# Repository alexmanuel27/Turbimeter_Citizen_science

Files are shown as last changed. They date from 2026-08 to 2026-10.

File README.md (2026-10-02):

# Citizen-science turbidimeter

This repository tracks a **single, quantitative turbidimeter prototype**. The
target is to have the instrument, Android app, calibration, and validation
ready by **18 October 2026**. Community deployment follows that date.

## Current design target

- **Sensor:** 850 nm IR LED, BPW34 photodiode at 90° for scattered light, and
  a second BPW34 to monitor the LED. An MCP6002 dual amplifier and ADS1115
  read the two channels; a Seeed XIAO SAMD21 controls the LED.
- **Readout:** the Android phone supplies power through USB-C, displays the
  result, and will offer optional upload to the citizen-science website. The
  instrument has no battery, screen, or status LEDs.
- **Enclosure:** closed body with a fixed 2 m USB-C data cable through one M12
  cable gland. The technician cuts the sensor-side plug, routes the cable,
  then terminates and tests power, USB data, and USB-C configuration wiring
  before sealing. The selected cable has a 5.5 ± 0.15 mm outer diameter;
  the gland grips 3–6.5 mm cable.
- **Output:** a numeric NTU value is a *goal*, not a property of the current
  firmware. Dark-corrected scattered/reference readings must first be
  calibrated with known standards and validated on independent samples.

The [optical and validation plan](docs/optical-design.md) describes the work
remaining. The [one-unit shopping list](docs/shopping-list-prototype-usb-c.xlsx)
is in English, shows VAT-inclusive prices and full supplier URLs as text, and
totals **€76.52** for priced items. Calibration standards require a quote;
delivery is excluded. The PCB and cuvettes are already available, so they are
not in the list. Confirm the lid groove before buying or using the selected
O-ring assortment.

## Repository status

| Path | Status |
| --- | --- |
| [`docs/optical-design.md`](docs/optical-design.md) | Current design and validation plan |
| [`docs/BOM.md`](docs/BOM.md) | Procurement notes; workbook above is the purchase list |
| [`firmware/xiao_samd21_turbimeter/`](firmware/xiao_samd21_turbimeter/) | Current XIAO optical bench firmware; reports diagnostic counts and an uncalibrated ratio over USB |
| [`firmware/firmware.ino`](firmware/firmware.ino) | Experimental optical-index sketch; still uses TL072 and status LEDs, so it is **not** the final USB-C/NTU firmware |
| [`android-app/`](android-app/) | Android USB-CDC screen/controller prototype with a XIAO SAMD21 communication test |
| [`firmware/legacy_sen0189/`](firmware/legacy_sen0189/) | Original DFRobot SEN0189 firmware, retained for reference |
| [`hardware/`](hardware/) and [`3D/`](3D/) | Earlier PCB and enclosure files; mechanical/electrical revisions are pending |
| [`docs/diagrams/legacy-circuit-schematic.svg`](docs/diagrams/legacy-circuit-schematic.svg) | Earlier TL072 circuit illustration, not a build schematic for this design |

The original SEN0189 prototype is shown below. It is superseded by the
discrete 90° optical design.

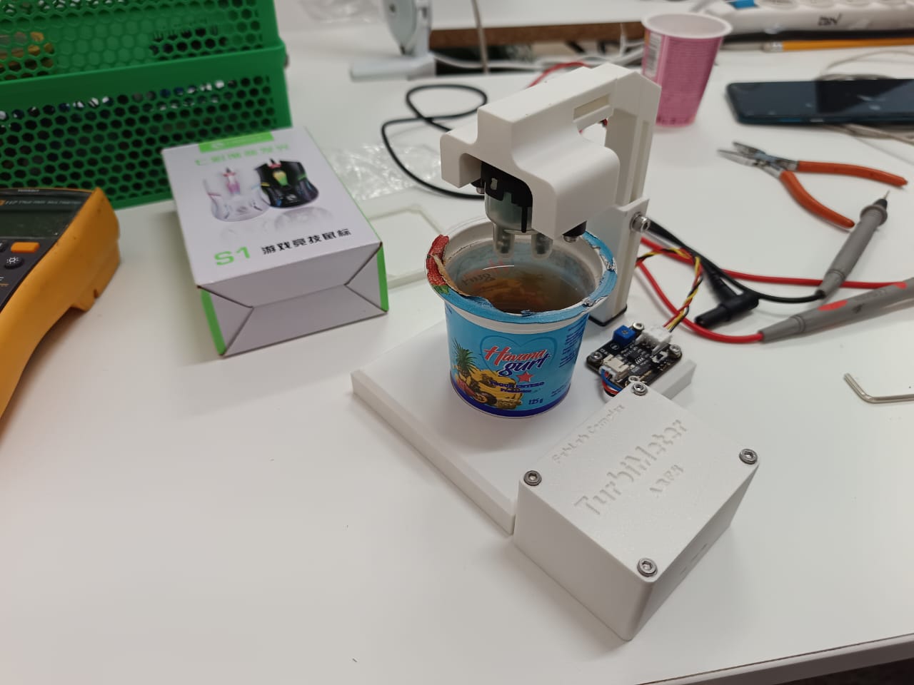
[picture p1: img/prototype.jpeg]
Earlier SEN0189 prototype


## Before 18 October

1. Bench-test the LED, both photodiodes, MCP6002, ADS1115, and feedback
   values with the actual sample chamber.
2. Revise the PCB and enclosure, choose a lid seal that fits the final groove,
   and verify USB-C power/data plus cable-gland sealing.
3. Test the new XIAO firmware and Android app together on a USB-C phone; add
   optional upload when the citizen-science API is specified.
4. Calibrate against known turbidity standards, quantify repeatability and
   error across the intended range, and only then enable NTU reporting.

Community deployment is the phase after 18 October.

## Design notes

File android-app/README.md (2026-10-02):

# Android app

The Android phone is the turbidimeter's screen and controller. This first
version connects to a USB-CDC XIAO SAMD21 and requests a reading. The side
menu has Home, History, Signature, and Privacy. Each real reading is saved automatically
in local History with its UTC timestamp and calibration status; History can be
shared as CSV. Demo readings are never saved. Signature stores
a self-declared contributor name and optional institution on the phone.
Privacy explains local data handling and lets the user delete saved data.

The **Upload reading** button appears on Home after a real reading. Uncalibrated
ratios cannot be uploaded. The citizen-science API is not defined yet, so the
app does not send data or request location permission. When the API is added,
each upload must use a fresh upload timestamp and phone location, with explicit
location permission, plus the saved contributor identity. Upload stays an
optional user action.

## Try it now

1. Flash [`usb_cdc_smoke_test.ino`](../firmware/usb_cdc_smoke_test/usb_cdc_smoke_test.ino)
   to the XIAO SAMD21 using the [Seeed Arduino setup](https://wiki.seeedstudio.com/Seeeduino-XIAO/).
2. Open this `android-app` folder in Android Studio, install Android SDK 36 if
   prompted, and run the app on an Android phone with USB host support.
3. Connect the XIAO with a **data-capable USB-C cable**. Tap **Connect sensor**,
   grant USB permission, then tap **Measure now**. The board sends a changing demo
   ratio; the app labels it as test data and does not allow saving it.

For the real optical bench, upload
[`xiao_samd21_turbimeter.ino`](../firmware/xiao_samd21_turbimeter/xiao_samd21_turbimeter.ino)
instead. It reads the ADS1115 and reports an uncalibrated ratio or a specific
sensor error. Its [wiring and test steps](../firmware/xiao_samd21_turbimeter/README.md)
must be checked before connecting the analog circuit.

For the final sealed instrument, the cable cut and passed through the gland
still needs a sound electrical termination at the board's USB-C connection.
Test the complete cable and the intended Android phone before sealing.

## Serial contract, version 1

The app sends one ASCII line: `MEASURE\n`. The device sends one ASCII line in
response. USB packets may split a line; the app assembles lines before parsing.

| Response | Meaning |
| --- | --- |
| `TURB1,DEMO,0.2500` | Synthetic value for testing USB and the screen |
| `TURB1,RATIO,0.2500` | Real optical ratio, still uncalibrated |
| `TURB1,RESULT,12.30,FNU,CAL-001,OK` | Future calibrated result with unit and calibration ID |
| `TURB1,ERROR,ADC_MISSING` | Example hardware error shown by the app |

The app rejects incomplete/nonfinite values and saves real `RATIO` and `RESULT`
frames automatically, recording their quality status in the CSV. The measurement firmware must not emit `RESULT` until its
calibration and valid measurement range have been verified. For this 850 nm
near-infrared design, decide the reportable unit and range during validation.

Saved readings remain private on the phone and can be shared manually as CSV.
The release app has no network permission or endpoint configured yet.

## Google Play preparation

See [`play-store/release-checklist.md`](play-store/release-checklist.md) for the
store assets, unsigned AAB build, privacy-policy draft, and remaining account,
signing, screenshots, and closed-testing steps.

## Check the parser without Android

With a JDK installed, run from `android-app`:

```sh
mkdir -p /tmp/turbimeter-parser
javac -d /tmp/turbimeter-parser app/src/main/java/org/citizenscience/turbimeter/{MeasurementFrame,LineFramer}.java test/MeasurementFrameCheck.java
java -ea -cp /tmp/turbimeter-parser org.citizenscience.turbimeter.MeasurementFrameCheck
```

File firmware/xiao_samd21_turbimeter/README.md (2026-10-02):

# XIAO SAMD21 optical firmware

Upload [`xiao_samd21_turbimeter.ino`](xiao_samd21_turbimeter.ino) to the
**original Seeed Studio XIAO SAMD21** (Arduino board: **Seeeduino XIAO**).
This is the current USB-C bench firmware. The older
[`firmware.ino`](../firmware.ino) targets a Nano/TL072/indicator-LED circuit;
do not upload it for this build.

## Planned wiring to verify with the electronics technician

| XIAO / sensor | Connection |
| --- | --- |
| USB-C | Power and USB CDC data from the Android phone or test computer |
| 3V3, GND | Common 3.3 V supply and ground for ADS1115 and MCP6002 |
| D4 (SDA), D5 (SCL) | ADS1115 I²C; ADDR to GND gives address `0x48` |
| D7 | Control of the current-limited 850 nm LED circuit |
| ADS1115 AIN0 | MCP6002 output from the 90° scatter photodiode |
| ADS1115 AIN1 | MCP6002 output from the LED reference photodiode |

**Do not reuse the old 5 V Nano wiring unchanged.** XIAO GPIO and I²C are
3.3 V. Power the ADS1115/MCP6002 analog circuit at 3.3 V for this test, and
confirm the LED resistor/driver current and both amplifier output ranges before
connecting them. The old PCB and drawing are not the final XIAO circuit.
See the [XIAO pin map](https://wiki.seeedstudio.com/Seeeduino-XIAO/),
[ADS1115 datasheet](https://www.ti.com/lit/ds/symlink/ads1115.pdf), and
[MCP6002 specifications](https://www.microchip.com/en-us/product/MCP6002).

## Upload and first tests

1. In Arduino IDE, add Seeed's boards URL
   `https://files.seeedstudio.com/arduino/package_seeeduino_boards_index.json`,
   install **Seeed SAMD Boards**, select **Seeeduino XIAO** and its USB port,
   then open this `.ino` and click **Upload**. The sketch needs only `Wire.h`.
2. With the XIAO connected to a computer, open Serial Monitor at **115200 baud**
   with **Newline** line ending. Send `PING`; expect `TURB1,PONG`. Send
   `MEASURE` before wiring the ADC; expect `TURB1,ERROR,ADC_MISSING`.
3. After wiring, send `DIAG`. The reply is
   `TURB1,DIAG,darkScatter,litScatter,darkReference,litReference,ratio`.
   The four signals are averaged ADS1115 counts (0.125 mV/count at the chosen
   gain). Check that the LED changes both channels, the reference difference
   is clearly above the noise, and neither input approaches 26000 counts.
4. Send `MEASURE`; expect `TURB1,RATIO,<number>`. Then connect the XIAO to an
   Android USB-C phone, tap **Connect sensor** and **Measure now** in the app.

The sketch takes four LED-off/on samples per request, subtracts the dark
signals, and divides corrected scatter by corrected reference. Adjust the two
`*_POLARITY` constants if an amplifier output falls rather than rises when
illuminated; use `DIAG` to decide. `MIN_REFERENCE_COUNTS`,
`SATURATION_COUNTS`, and `LED_SETTLE_MS` are bench settings to revisit after
measuring the actual circuit. I²C failures, weak reference, negative scatter,
and near-rail signals return explicit `TURB1,ERROR,...` messages to the app.

**Bench result, 2 October 2026:** this sketch uploaded and verified on the
connected XIAO. `PING` returned `TURB1,PONG`; `MEASURE` and `DIAG` both
returned `TURB1,ERROR,ADC_MISSING`, as expected with only the XIAO plugged in.
The ADS1115 and optical circuit were not connected, so no optical reading has
been verified yet.

**The ratio is not turbidity in FNU/NTU.** The firmware deliberately sends no
`TURB1,RESULT` until standards, a calibration curve, valid range, and
independent-sample checks have been completed. The XIAO USB link has been
checked; ADC and optical readings still need physical verification.

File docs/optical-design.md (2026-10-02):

# Optical design and validation plan

## Target and status

Build one closed turbidimeter that an Android USB-C phone powers and reads.
The app will show a quantitative turbidity value and optionally upload it to the
citizen-science website. The instrument has no battery, screen, or status
LEDs. **The optical bench, firmware, app, and NTU calibration are not yet
validated.** They must be ready before 18 October 2026; community deployment
comes afterward.

The DFRobot SEN0189 sensor and its firmware are retained only as an earlier
prototype. The current KiCad PCB and 3D files also predate this design. The
[one-unit purchase list](shopping-list-prototype-usb-c.xlsx) is the source for
current parts, supplier URLs, and VAT-inclusive prices.

## Optical and electrical concept

90-degree optical geometry

An 850 nm IR LED illuminates the sample. One BPW34 photodiode measures light
scattered at 90°; a second, shielded from the sample, monitors the LED. Read
both photodiodes with the LED off and on, subtract the dark readings, and form
a scattered/reference ratio. This ratio compensates for some changes in LED
output, but **it is not an NTU value** by itself.

The intended signal chain is:

| Stage | Planned part / connection |
| --- | --- |
| Illumination | 850 nm IR LED controlled by XIAO SAMD21 D7 through a verified current-limited circuit |
| Detection | Two BPW34 photodiodes: 90° scatter and shielded reference |
| Amplification | MCP6002 dual amplifier at 3.3 V; start with 1 MΩ feedback resistors and tune using measured signal levels |
| Conversion | ADS1115 at 3.3 V, with the two amplifier outputs on AIN0 and AIN1; I²C to XIAO D4/D5 |
| Phone interface | USB-C XIAO SAMD21, data-capable 2 m USB-C cable, Android USB host app |

Prototype the analog chain and verify input range, saturation, ambient-light
rejection, and repeatability before revising the PCB. The old
[`legacy-circuit-schematic.svg`](diagrams/legacy-circuit-schematic.svg) uses a
TL072 and status LEDs; it is **not** a schematic for this build. Likewise,
[`firmware/firmware.ino`](../firmware/firmware.ino) is the older sketch that
outputs a relative index and controls LEDs. The current USB bench sketch is
[`xiao_samd21_turbimeter.ino`](../firmware/xiao_samd21_turbimeter/xiao_samd21_turbimeter.ino).

## Enclosure and USB cable

Use the Goobay 66508 USB-C-to-USB-C data cable (2 m). Its specified outer
diameter is **5.5 ± 0.15 mm**; the selected TinyTronics M12 gland clamps
**3–6.5 mm** cable. Cut the device-side plug, pass the cable through the
gland, and terminate USB power, USB 2.0 data, and the required USB-C CC
connection to the board. Confirm continuity, Android USB host operation,
strain relief, and sealing before closing the enclosure. Verify final lid
dimensions before selecting an O-ring from the assortment (maximum 28 mm
inner diameter).

## From optical ratio to reliable NTU

1. Fix the final optical geometry and record LED-off/LED-on readings from both
   channels, including the clear-water background.
2. Measure known turbidity standards spanning the intended range with the
   same sample vessels and handling procedure. The Hanna HI98703-11 set is a
   purchase candidate; check ULB stock, vessel compatibility, and quote.
3. Fit a calibration curve only after inspecting the measured response.
   Store its coefficients and calibration identity with the device/app data.
4. Check independent samples and repeat measurements. Record the range,
   error, repeatability, drift, and any region where the sensor saturates.
5. Show/upload NTU only when the calibration is valid for that range; otherwise
   label the reading as an uncalibrated optical ratio or out of range.

The Android app prototype is present, but the citizen-science API has not yet
been specified. Upload must remain optional. A published measurement record
should include the reading, unit, calibration identity, timestamp, and quality
status.

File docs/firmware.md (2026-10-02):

# Firmware explanation (legacy SEN0189 design)

> ⚠️ **Legacy.** This describes the original DFRobot SEN0189-based sensor,
> now superseded by a custom discrete 90° nephelometric design — see
> [docs/optical-design.md](optical-design.md). Kept for reference; the code
> itself lives in [`firmware/legacy_sen0189/firmware.ino`](../firmware/legacy_sen0189/firmware.ino).

The current XIAO SAMD21 sketch and upload instructions are in
[`firmware/xiao_samd21_turbimeter/`](../firmware/xiao_samd21_turbimeter/).

Analysis of [`firmware/legacy_sen0189/firmware.ino`](../firmware/legacy_sen0189/firmware.ino):
DFRobot SEN0189 turbidity sensor + Arduino Nano.

## Hardware wiring

| Sensor wire | Destination |
|---|---|
| Red (VCC) | 5V |
| Black (GND) | GND |
| Blue (analog signal) | Pin A1 |



*Sensor wiring diagram. Source: DFRobot Wiki (official).*

There are also 3 indicator LEDs (green/yellow/red) on configurable digital
pins (10, 9, and 8 by default) to visually show the turbidity level without
needing to watch the Serial Monitor.

## General logic (`loop`)

1. **Reading the sensor:** instead of taking a single analog reading (which
   would be noisy), it averages **800** consecutive `analogRead(A1)` samples
   with a small pause between each one (`delayMicroseconds(500)`). This
   stabilizes the value before it's used.
2. **Converting to voltage:** the average (0–1023, 10-bit ADC resolution) is
   scaled to a real voltage using the Arduino's 5V reference:
   `voltage = average * (5.0 / 1023.0)`.
3. **Converting to NTU:** a second-degree polynomial formula
   (`ntu = A*v² + B*v + C`) is applied, with coefficients taken from the
   Arduino community (not an official DFRobot value — the manufacturer only
   publishes a reference graph, not an equation). Below 2.5V, maximum
   turbidity (3000 NTU) is assumed, since the sensor's curve is no longer
   reliable in that range.
4. **Output:** the voltage and NTU value are printed to the Serial Monitor,
   and if not currently calibrating, the corresponding "level" is evaluated
   to turn on the right LED.

## Why there's a calibration wizard

Since the NTU formula is just a generic approximation, the code doesn't
trust it to decide when to turn on each LED. Instead, it lets you calibrate
the **thresholds** using real water samples from the actual sensor:

1. Type `C` in the Serial Monitor to start.
2. You're asked to dip the sensor in **clear water**, fixed with `F`.
3. You're asked for **medium turbidity water** (suggests yellow dye), fixed
   with `F`.
4. You're asked for **high turbidity water** (suggests coffee or dark ink),
   fixed with `F`.
5. You finish with `X`, which:
   - Calculates the thresholds as the midpoint between each pair of samples
     (`recalculateThresholds()`).
   - Saves the 3 reference NTU values to the Arduino's **EEPROM**
     (`saveCalibrationToEEPROM()`), so the calibration isn't lost when the
     device is powered off.

On power-up, `loadCalibrationFromEEPROM()` checks whether a calibration was
already saved (using a "flag" at EEPROM address 12) and, if so, loads it
instead of using the default values.

## LED logic (`evaluateLeds`)

With the 3 calibrated points (clear / medium / turbid), two intermediate
thresholds are calculated:

- `MEDIUM_TURBIDITY_THRESHOLD` = midpoint between "clear" and "medium"
- `HIGH_TURBIDITY_THRESHOLD` = midpoint between "medium" and "turbid"

Then:

- NTU > `HIGH_TURBIDITY_THRESHOLD` → **red LED** (high turbidity)
- NTU > `MEDIUM_TURBIDITY_THRESHOLD` → **yellow LED** (medium turbidity)
- otherwise → **green LED** (low turbidity)

## Notes for anyone modifying the code

- The LED pins (`RED_LED_PIN`/`YELLOW_LED_PIN`/`GREEN_LED_PIN`) are marked
  in the code as `<-- CHANGE` because they depend on how each board is
  wired.
- `NUMBER_OF_SAMPLES = 800` is a trade-off between reading stability and
  refresh speed (more samples = more precise but slower refresh, currently
  about every 0.5s plus sampling time).
- The `COEF_A/B/C` coefficients should only be touched if you run your own
  regression with real NTU values (e.g. with a reference turbidimeter) —
  something still pending for this project. Today, reliability comes from
  the manually calibrated thresholds, not from the formula.

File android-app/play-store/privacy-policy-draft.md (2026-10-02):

# Privacy Policy — Turbimeter

**Draft: fill in the publisher name and public contact email, then host this page at a public, non-editable URL before submitting to Google Play.**

Publisher: [Play Console publisher name]

Privacy contact: [public contact email]

Turbimeter is a companion app for a compatible USB-C water turbidity sensor. It communicates with the sensor when you tap Connect sensor and grant Android's USB permission.

## Data stored on your phone

The app stores readings in its private app storage: UTC time, value, unit, quality status, and calibration identifier. If you fill in Signature, it stores your name and optional institution or group in private app preferences. The app does not create an account or store your precise location.

## Network and sharing

This version does not automatically send readings or profile details to the publisher or a server. It does not include advertising or analytics SDKs. If you choose Share readings (CSV), Android opens a sharing chooser and passes the CSV to the app you select. That recipient's privacy practices then apply to the copy you shared.

## Retention and deletion

Readings and Signature details remain on your phone until you select Privacy > Delete all local data or uninstall the app. Android backup is disabled for this app. We do not retain a server copy because this version has no upload service.

## Security

The data is kept in Android app-private storage. The app has no release-version internet permission. Access to the USB sensor requires the permission shown by Android.

## Questions and changes

Contact [public contact email] or use the [project issue tracker](https://github.com/alexmanuel27/Turbimeter_Citizen_science/issues). If a future version adds online upload or location access, this policy and the Play Data safety declaration must be updated before release.

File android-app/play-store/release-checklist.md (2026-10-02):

# Google Play release handoff

Current package ID: `org.citizenscience.turbimeter`. Confirm this in Play Console before the first upload; the package ID cannot be changed for that listing. The prototype installed directly on the Samsung used this same ID with a debug key, so it may need to be uninstalled before installing the Play-signed app. Back up any CSV first.

## Prepared in this repository

- Android 16 / API 36 target, as required for new Play submissions from 31 August 2026.
- Release AAB build task: `./gradlew bundleRelease` (currently unsigned).
- No internet or location permission in the release app; debug bridge removed.
- In-app Privacy page and local-data deletion control.
- Store listing draft and correctly sized icon and feature graphic in `assets/`.

## Still required before a Play submission

1. Create and verify the Play Console developer account. Choose the final publisher name and public contact email.
2. Replace the placeholders in `privacy-policy-draft.md`, host it at a public web URL, and enter that URL in Play Console. Check that the in-app policy still matches the release build.
3. Create and safely store a private upload key outside the repository. Use Android Studio's **Generate Signed Bundle / APK** wizard to sign the AAB and enroll in Play App Signing. Never commit the keystore or passwords.
4. Enter the store listing text, icon, feature graphic, and at least two genuine phone screenshots. State that a compatible external USB-C sensor is required and that this version saves locally rather than uploading.
5. Complete the Data safety form, content rating, target audience, ads declaration, and any other Play Console app-content forms. Based on the current release code, readings and Signature data stay on-device; manual CSV sharing is user-initiated. Recheck this declaration against the final artifact.
6. Test the signed release on a phone with the actual sensor. Verify USB permission, measurement, History, CSV share, Signature, privacy page, deletion, and app restart. A calibrated result must be validated against reference standards before the listing claims quantitative turbidity.
7. If the new account is personal, run Google's required closed test with at least 12 opted-in testers for 14 continuous days, then request production access.

Online API upload and location capture are not implemented in this version. They must not be claimed in the Play listing or Data safety form.

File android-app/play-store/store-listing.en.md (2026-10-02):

# Turbimeter — Google Play listing draft

## App name

Turbimeter

## Short description

View and save readings from a compatible USB-C water turbidity sensor

## Full description

Turbimeter turns an Android phone into the display and field log for the ARES Cuban Water Lab USB-C turbidity sensor. A compatible external sensor is required; the app cannot measure water on its own.

Connect the sensor, request a reading, and see its status on screen. Real readings are saved on the phone with a UTC timestamp and can be exported as CSV. The app distinguishes an uncalibrated optical ratio from a calibrated turbidity result. A ratio must not be interpreted as an FNU or NTU value.

The current version works offline. It has no automatic upload, account, advertising, or analytics. The contributor name and optional group entered in Signature stay on the phone. Online submission is planned for a later version.

This app is for the compatible citizen-science instrument. Measurement reliability depends on the sensor hardware and its calibration; do not use uncalibrated readings to make water safety decisions.

## Screenshot plan

Capture at least two genuine screenshots from the release app on an Android phone. Show Home with a real sensor connected and History with a real saved reading. Do not use the debug example screen as a store screenshot.

## Graphic alt text

- Icon: ARES Cuban Water Lab logo with a water wave and optical sensor symbol.
- Feature graphic: Blue water layers crossed by a warm light beam and scattering rings.

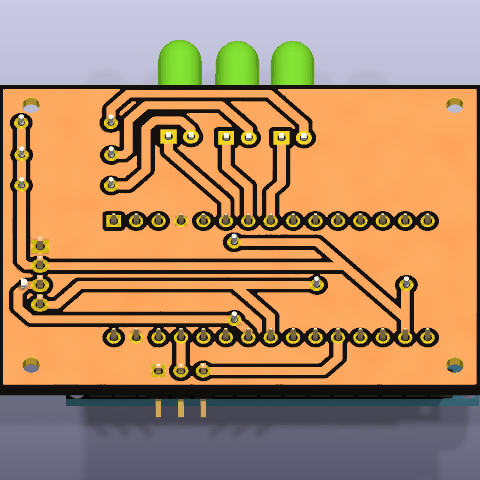
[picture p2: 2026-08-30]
img/pcb_rotation.gif

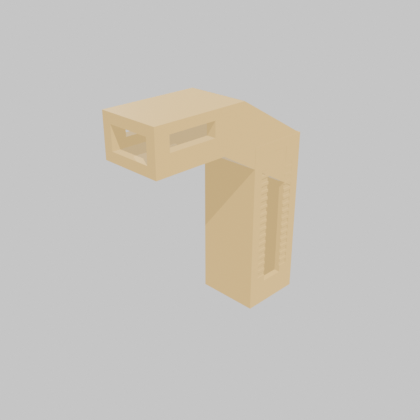
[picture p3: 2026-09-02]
img/3d/neck.gif

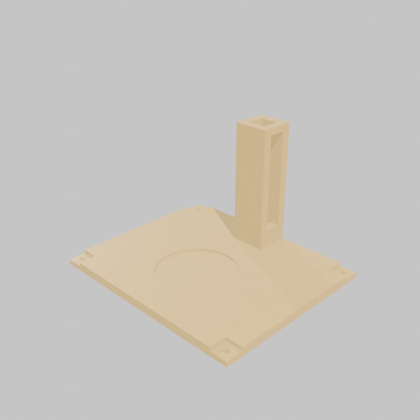
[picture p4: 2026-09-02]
img/3d/lid.gif

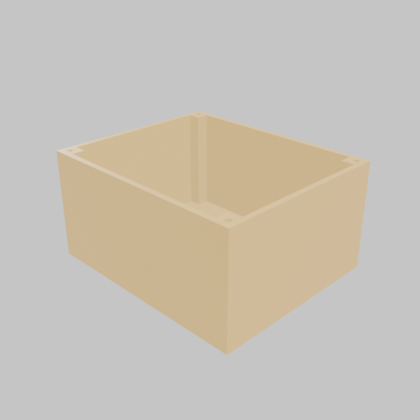
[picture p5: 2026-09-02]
img/3d/case.gif

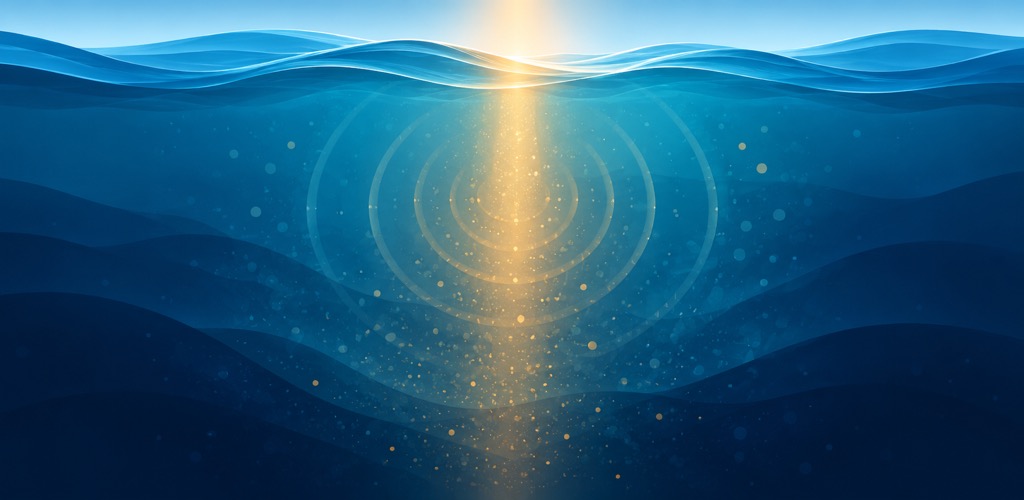
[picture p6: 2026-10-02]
android-app/play-store/assets/feature-1024x500.jpg

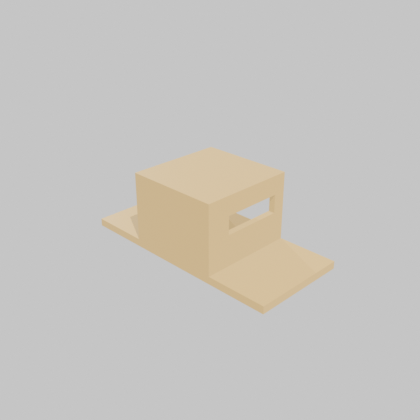
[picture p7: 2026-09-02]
img/3d/sensor_holder.gif

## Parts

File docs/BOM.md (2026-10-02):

# Prototype purchase list

The current purchasing file for **one Android USB-C turbidimeter** is
[`shopping-list-prototype-usb-c.xlsx`](shopping-list-prototype-usb-c.xlsx).
It has one row per product, supplier references, quantities, full product URLs
as plain text, and prices **including VAT** (checked 29 September 2026).

The priced subtotal is **€76.52 including VAT**. This excludes delivery and
the Hanna HI98703-11 turbidity standards, for which a VAT-inclusive quote is
still needed. Check ULB stock before ordering; the spreadsheet starts with
zero stock as an editable placeholder.

The list covers the IR LED, two BPW34 photodiodes, MCP6002, ADS1115, passives,
2 m USB-C data cable, one M12 gland, and a metric O-ring
assortment. The cable's manufacturer specifies a 5.5 ± 0.15 mm outer
diameter, within the M12 gland's 3–6.5 mm clamping range. Check the final lid
groove: the selected O-ring kit reaches only 28 mm inner diameter.

The workbook still lists a USB-C Nano. That board has been superseded by the
**XIAO SAMD21 already in hand**; do not order the Nano for this firmware.

The existing PCB and cuvettes are on hand. No battery, display, status LEDs,
separate turbidimeter, or additional gland sizes are included. The current PCB
layout is from the earlier SEN0189 design and still requires revision.

Cable diameter source, Goobay 66508 manufacturer datasheet:
https://www.wentronic.com/media/perfion/perfion-product/66508_Produkt-Datenblatt%23Product-Data-Sheet.pdf

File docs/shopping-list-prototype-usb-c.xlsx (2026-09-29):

Item | Reference / SKU | Needed | Units/pack | ULB stock | Packs to order | Supplier | €/pack incl VAT | Total incl VAT | Link | Technical note
850 nm IR LED, 5 mm | RS 699-7694 / TSHG6410 | 1 | 20 | 0 | 1 | RS | €16.80 | €16.80 | https://benl.rs-online.com/web/p/ir-leds/6997694 | Pack of 20; test LED current and optical geometry.
BPW34 photodiode | RS 699-7616 / BPW34 | 2 | 5 | 0 | 1 | RS | €7.03 | €7.03 | https://benl.rs-online.com/web/p/photodiodes/6997616 | Two channels: 90° scatter and reference.
MCP6002-E/P dual op amp, DIP-8 | RS 352-239 | 1 | 10 | 0 | 1 | RS | €5.40 | €5.40 | https://benl.rs-online.com/web/p/op-amps/0352239 | Test the transimpedance amplifiers at 5 V.
ADS1115 module, I²C, 16-bit | Tiny 006632 | 1 | 1 | 0 | 1 | TinyTronics | €5.50 | €5.50 | https://www.tinytronics.nl/en/sensors/current-voltage/ads1115-adc-module-16-bit-i2c-4-channels | Confirm connection and fit with the existing PCB.
Nano V3.0 compatible, USB-C | Tiny 004270 | 1 | 1 | 0 | 1 | TinyTronics | €7.00 | €7.00 | https://www.tinytronics.nl/en/development-boards/microcontroller-boards/arduino-compatible/nano-v3.0-usb-c-compatible-separate-headers | Phone supplies 5 V and receives serial data.
1 MΩ resistors, 1%, ¼ W | Tiny 007629 | 2 | 10 | 0 | 1 | TinyTronics | €0.50 | €0.50 | https://www.tinytronics.nl/en/components/resistors/resistors/resistor-1m%CF%89-1-4w-10-pieces | Initial feedback value; tune both optical channels.
220 Ω resistor, ¼ W | Tiny pack of 10 | 1 | 10 | 0 | 1 | TinyTronics | €0.50 | €0.50 | https://www.tinytronics.nl/en/components/resistors/resistors/resistor-220%CF%89-1-4w-10-pieces | One resistor for the IR LED.
Capacitor kit, 2 pF–100 nF | Tiny 000297 / CERCONSET | 1 | 1 | 0 | 1 | TinyTronics | €4.00 | €4.00 | https://www.tinytronics.nl/en/components/capacitors/ceramic-capacitor-set-2pf-100nf | For amplifier stability tuning during bench tests.
100 nF, 50 V ceramic capacitor | Tiny 000226 | 3 | 1 | 0 | 3 | TinyTronics | €0.10 | €0.30 | https://www.tinytronics.nl/en/components/capacitors/100nf-50v-ceramic-capacitor | Supply decoupling; confirm placement on the existing PCB.
USB-C to USB-C data cable, 2 m | Tiny 003273 / Goobay 66508 | 1 | 1 | 0 | 1 | TinyTronics | €9.00 | €9.00 | https://www.tinytronics.nl/en/cables-and-connectors/cables-and-adapters/usb/usb-c/goobay-66508-usb-c-usb-c-3.1-cable-2m-3a-black | Cut sensor-side plug; pass cable through gland. Reterminate USB 2.0 power/data and CC per board pinout; continuity-test before sealing.
Metric nitrile O-ring assortment, 385 pcs | RS 705-8958 | 1 | 1 | 0 | 1 | RS | €19.89 | €19.89 | https://benl.rs-online.com/web/p/seal-o-ring-kits/7058958 | For lid seal; kit sizes only reach 28 mm inner diameter. Check final groove size.
Cable gland M12, 3–6.5 mm | Tiny 003009 / CABLEGLANDM12 | 1 | 1 | 0 | 1 | TinyTronics | €0.60 | €0.60 | https://www.tinytronics.nl/en/tools-and-mounting/installation-and-mounting-material/cable-glands/cable-gland-m12-3mm-6.5mm | Fits Goobay 66508 cable OD 5.5 ± 0.15 mm; confirm enclosure hole and panel thickness.
Turbidity standards <0.1 / 15 / 100 / 750 NTU | Hanna HI98703-11 | 1 | 1 | 0 | 1 | Hanna BE |  |  | https://www.hannainstruments.be/nl/kalibratieset-voor-de-hi98703-en-hi93414-turbiditeitsmeters-01-15-100-en-750-ntu-hi98703-11/ | Check ULB stock; request VAT-inclusive quote and confirm compatibility with existing cuvettes.
Priced items subtotal (incl VAT) |  |  |  |  |  |  |  | €76.52 |  | Excludes unpriced standards and delivery.

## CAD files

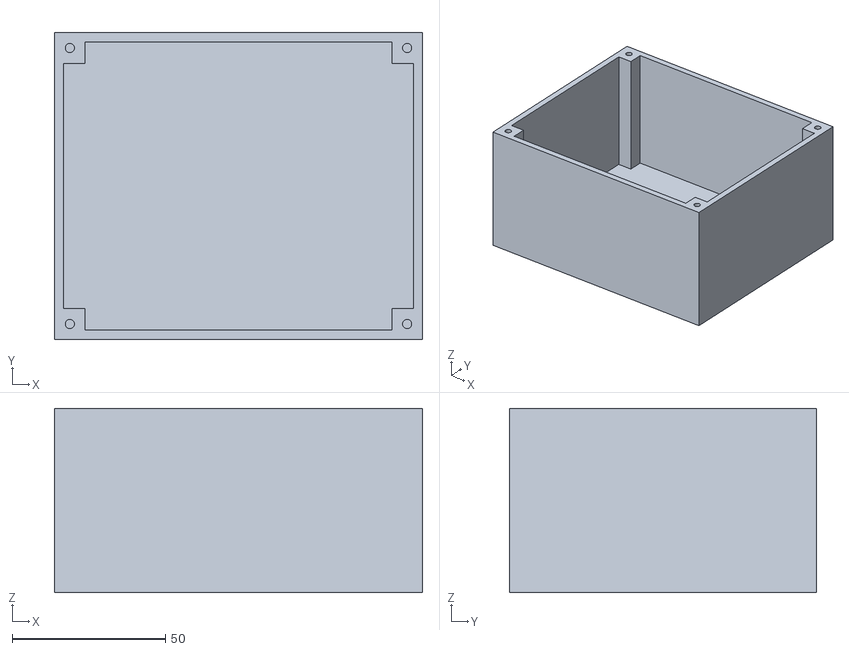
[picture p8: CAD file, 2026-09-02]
3D/CASE.stl
120.0 x 100.0 x 60.0

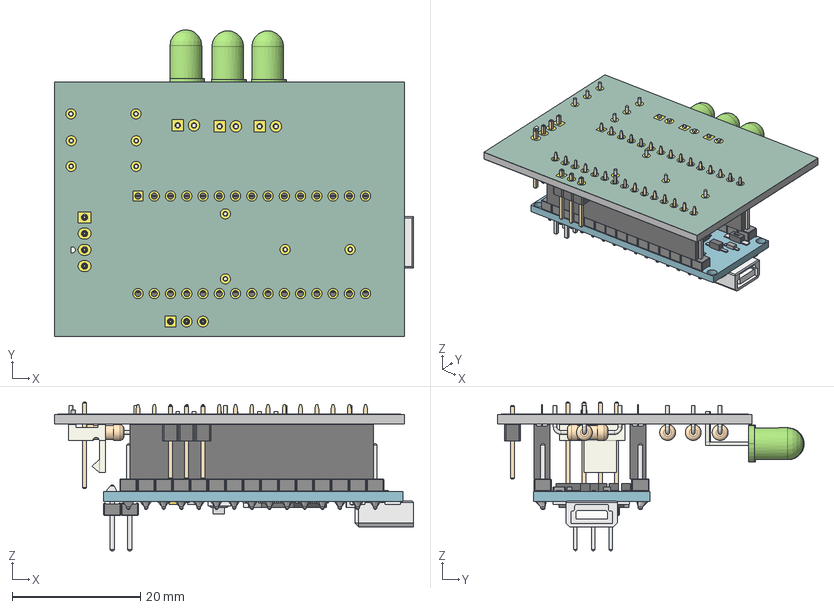
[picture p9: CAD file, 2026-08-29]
hardware/esque.step
56.1 x 47.9 x 23.2 mm
FanPinHeader_1x04_P2.54mm_Vertical
PinSocket_1x15_P2.54mm_Vertical x 2
Pin Headers x 36
IC
Switch
Joints
USB Mini Port
Main Board + USB
IC joint small
Text
Bottom ICs
Solder Joint
R_Axial_DIN0207_L6.3mm_D2.5mm_P10.16mm_Horizontal x 5
LED_D5.0mm_Horizontal_O6.35mm_Z3.0mm x 3
PinHeader_1x03_P2.54mm_Vertical
esque_copper
esque_silkscreen
esque_soldermask x 2
esque_PCB

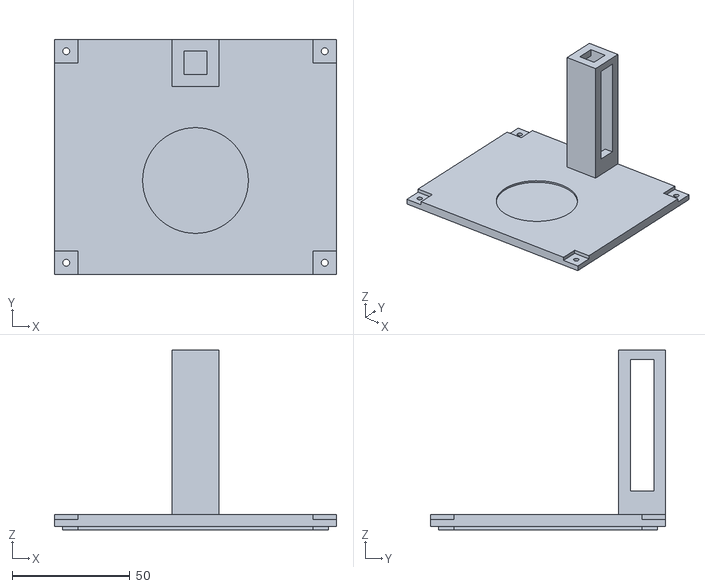
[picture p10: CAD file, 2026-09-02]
3D/LID.stl
120.0 x 100.0 x 76.5

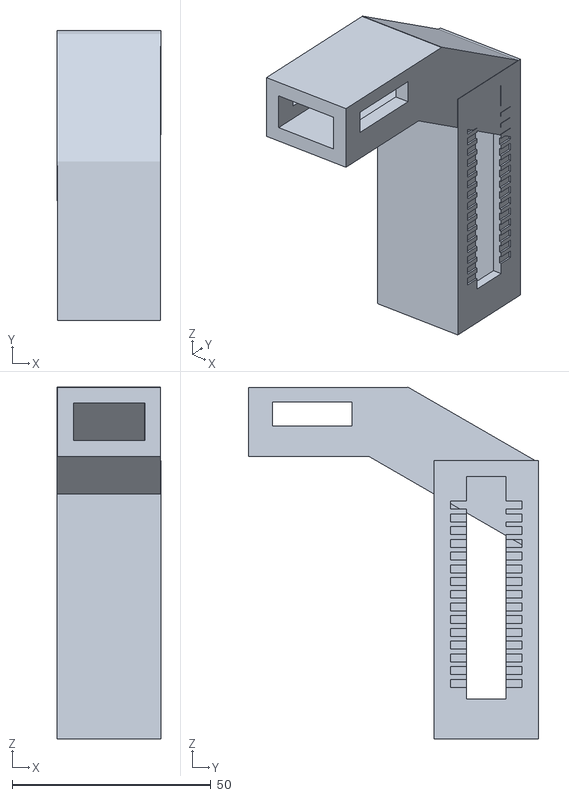
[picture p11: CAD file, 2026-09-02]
3D/NECK.stl
26.2 x 72.8 x 88.5

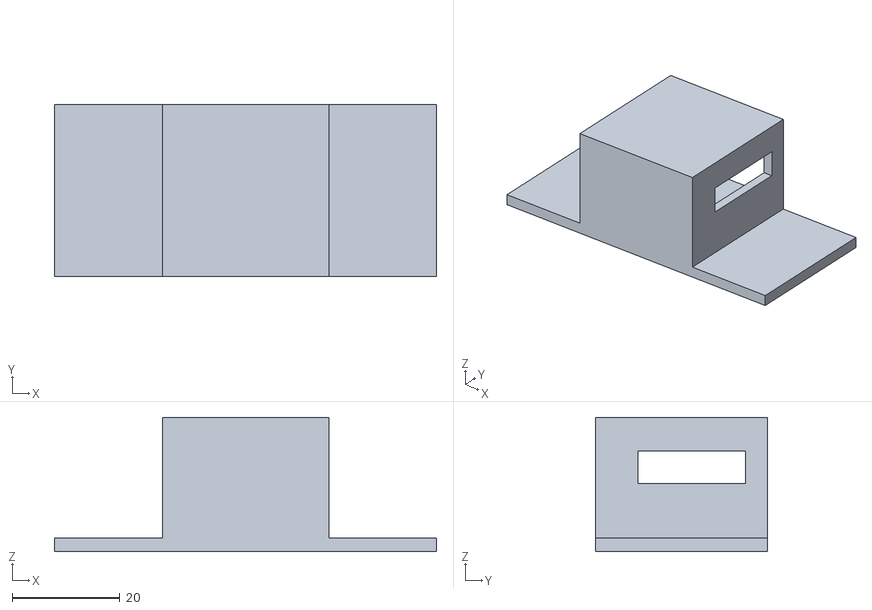
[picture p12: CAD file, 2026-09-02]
3D/SENSOR-HOLDER.stl
71.1 x 32.0 x 24.9

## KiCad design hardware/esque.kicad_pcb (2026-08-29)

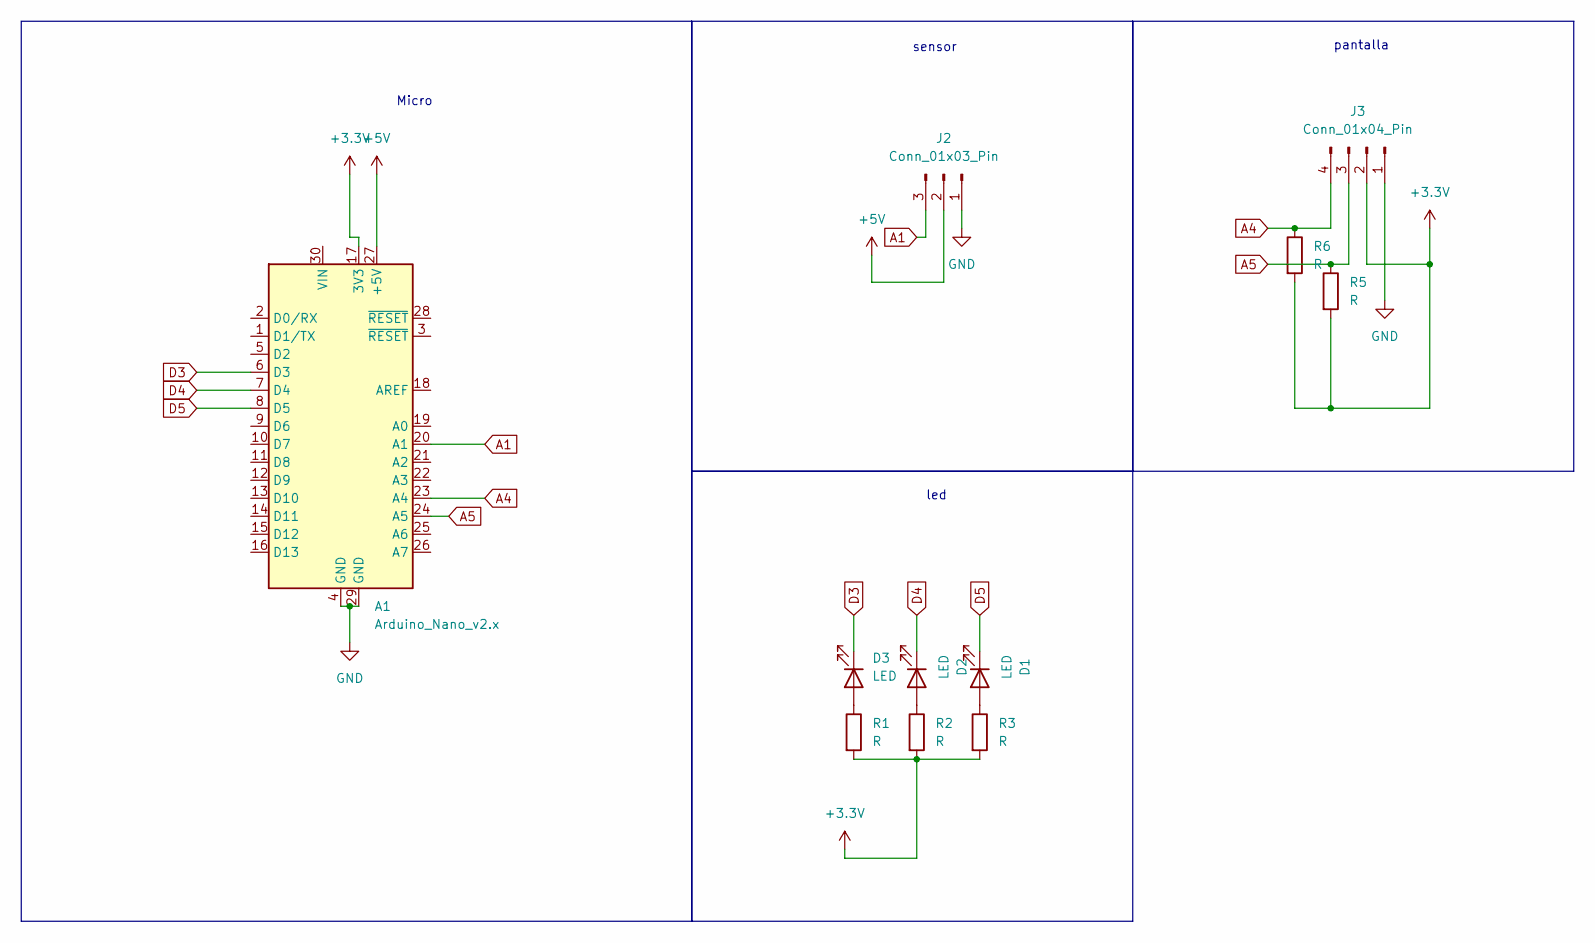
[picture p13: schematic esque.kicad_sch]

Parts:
A1: Arduino_Nano_v2.x; Arduino_Nano
D1, D2, D3: LED; LED_D3.0mm_Horizontal_O6.35mm_Z10.0mm
J2: Conn_01x03_Pin; PinHeader_1x03_P2.54mm_Vertical
J3: Conn_01x04_Pin; FanPinHeader_1x04_P2.54mm_Vertical
R1, R2, R3, R5, R6: R; R_Axial_DIN0207_L6.3mm_D2.5mm_P10.16mm_Horizontal

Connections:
+3.3V: A1.17 (3V3), J3.2, R1.2, R2.2, R3.2, R5.2, R6.2
+5V: A1.27 (+5V), J2.2
A1: A1.20 (A1), J2.3
A4: A1.23 (A4), J3.4, R6.1
A5: A1.24 (A5), J3.3, R5.1
D3: A1.6 (D3), D3.1 (K)
D4: A1.7 (D4), D2.1 (K)
D5: A1.8 (D5), D1.1 (K)
GND: A1.4 (GND), A1.29 (GND), J2.1, J3.1
unnamed: D1.2 (A), R3.1
unnamed: D2.2 (A), R2.1
unnamed: D3.2 (A), R1.1

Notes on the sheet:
sensor
Micro
led
pantalla

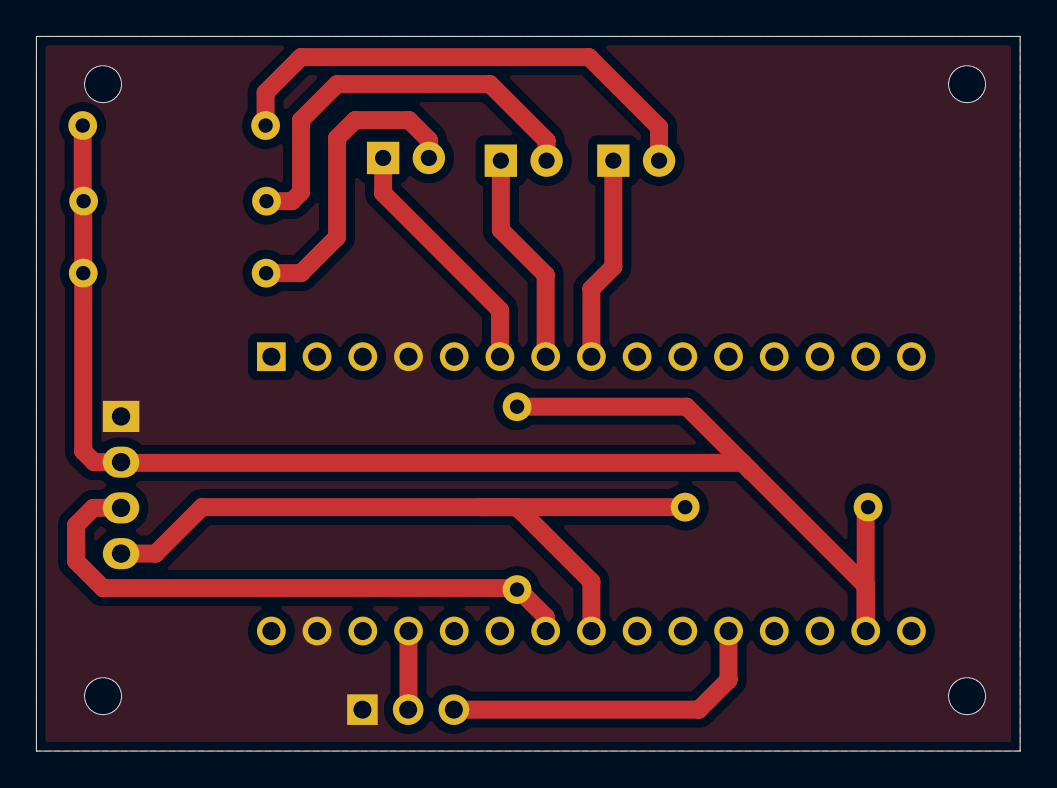
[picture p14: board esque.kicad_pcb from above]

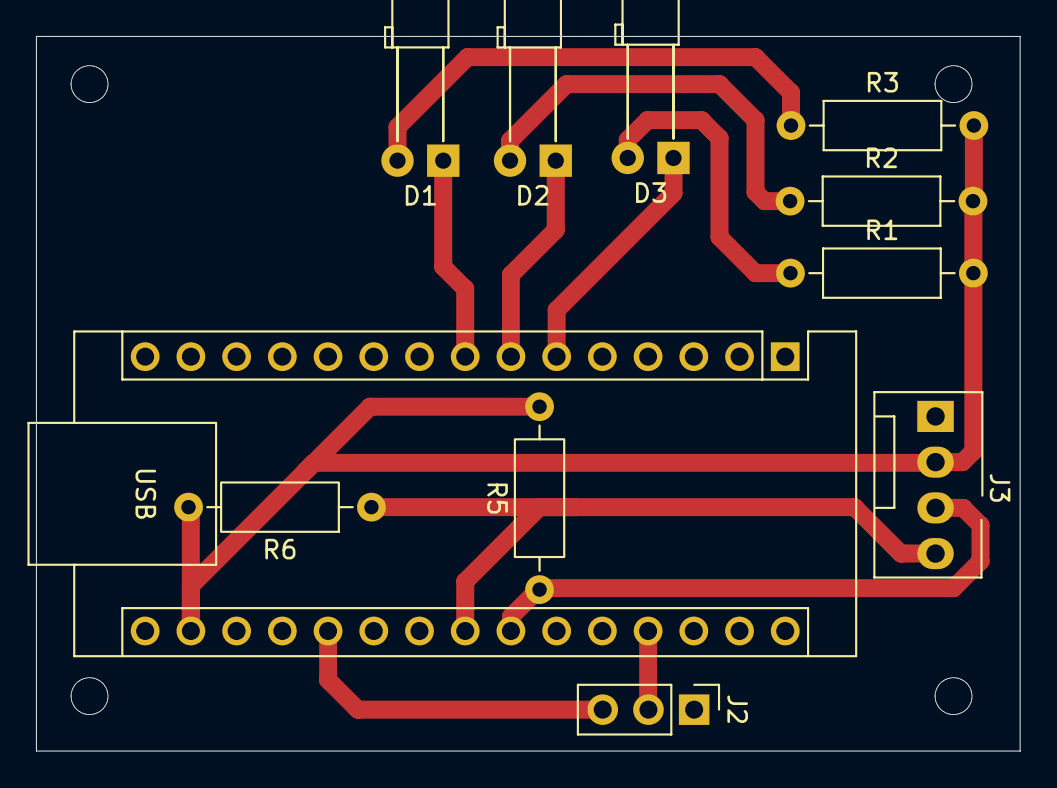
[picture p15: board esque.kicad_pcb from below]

Board: 2 copper layers, 54.6 x 39.7 mm, 11 parts (11 on the bottom side), 12 nets.

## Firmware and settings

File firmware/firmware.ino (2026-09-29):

/*
  EXPERIMENTAL PRE-USB OPTICAL-INDEX SKETCH, NOT FINAL NTU FIRMWARE.
  This version still uses a TL072 and status LEDs. The current one-unit
  design target uses MCP6002, no status LEDs, and an Android USB-C app.
  See docs/optical-design.md before building or changing this sketch.

  ============================================================
   DISCRETE 90 DEGREE NEPHELOMETRIC TURBIDITY SENSOR
   ARDUINO NANO + IR LED + 2x BPW34 PHOTODIODE + TL072 + ADS1115
  ============================================================
  Description:
   Replaces the DFRobot SEN0189 module with a custom optical
   bench: an IR LED shines into the sample, a photodiode placed
   at 90 DEGREES from the LED picks up SCATTERED light
   (nephelometry, same principle as ISO 7027 turbidimeters),
   and a second "reference" photodiode near the LED tracks the
   LED's own brightness so drift (temperature, aging) cancels
   out. Both photodiode signals are amplified by a transimpedance
   op-amp (TL072) and read through an external 16-bit ADC
   (ADS1115) instead of the Nano's own 10-bit ADC.

   Full schematic, optical geometry, part numbers and purchase
   links: docs/optical-design.md and docs/diagrams/*.svg

  *** WHY THIS INSTEAD OF THE OLD SEN0189 FORMULA ***
   The old firmware (see firmware/legacy_sen0189/) computed a
   fake "NTU" from a straight-through (0 degree) analog reading
   using a generic community formula with no physical basis, and
   read it through the Nano's noisy 10-bit ADC. This version
   reports an honest, uncalibrated TURBIDITY INDEX instead of a
   fabricated NTU number - it is NOT yet an absolute NTU value.
   Turning it into real NTU requires calibrating against a
   reference instrument or formazin standards (see
   docs/optical-design.md, section "Getting to absolute NTU").

  Wiring summary (see docs/diagrams/legacy-circuit-schematic.svg):
   - IR LED (850nm)  -> D7 through a 220ohm resistor -> GND
   - Photodiode A (measurement, at 90 degrees) -> TL072 channel A
     (transimpedance amp) -> ADS1115 AIN0
   - Photodiode B (reference, near the LED)    -> TL072 channel B
     (transimpedance amp) -> ADS1115 AIN1
   - ADS1115: VDD->5V, GND->GND, ADDR->GND (I2C address 0x48),
     SDA->Nano A4, SCL->Nano A5

  REQUIRED LIBRARIES:
   - None beyond what ships with the Arduino IDE. <Wire.h> is
     used for I2C, talking to the ADS1115 directly via its
     register interface (no Adafruit_ADS1X15 dependency), the
     same "no external library" philosophy as the original
     firmware. <EEPROM.h> is used to store the calibration.

  ============================================================
                 CALIBRATION GUIDE (Serial Monitor)
  ============================================================
   1. Open the Serial Monitor (Ctrl+Shift+M) at 9600 baud.
   2. Type the letter  C  and press Enter -> starts calibration.
   3. The program will ask you to dip the sensor in CLEAR water
      (pure water). Wait for the reading to stabilize and type
      F  + Enter to fix that point.
   4. Then it will ask for WATER WITH YELLOW DYE (medium turbidity).
      Dip the sensor, wait for it to stabilize, and type
      F  + Enter to fix that point.
   5. Then it will ask for WATER WITH DISSOLVED COFFEE OR DARK INK
      (high turbidity). Dip the sensor, wait for it to stabilize,
      and type  F  + Enter to fix that point.
   6. Finally type  X  + Enter to FINISH the calibration. The
      values are calculated and automatically saved to EEPROM.
  ============================================================
*/

#include <Wire.h>
#include <EEPROM.h>

// ------------------- PIN CONFIGURATION -------------------

const int LED_DRIVE_PIN = 7; // Drives the IR LED (through a 220ohm resistor)

// >>> SET THE DIGITAL PINS YOU'RE ACTUALLY USING HERE <<<
const int RED_LED_PIN    = 8;   // <-- CHANGE: status RED LED digital pin
const int YELLOW_LED_PIN = 9;   // <-- CHANGE: status YELLOW LED digital pin
const int GREEN_LED_PIN  = 10;  // <-- CHANGE: status GREEN LED digital pin

const int SAMPLES_PER_READING = 8; // ADS1115 reads to average per state (dark/lit)
const int LED_SETTLE_MS = 5;       // Wait after switching the LED before reading

// ------------------- ADS1115 (RAW I2C, NO LIBRARY) -------------------
const uint8_t ADS1115_ADDRESS = 0x48;      // ADDR pin tied to GND
const uint8_t ADS1115_REG_CONVERSION = 0x00;
const uint8_t ADS1115_REG_CONFIG = 0x01;
const int MEASUREMENT_CHANNEL = 0; // AIN0 <- photodiode A (90 degrees)
const int REFERENCE_CHANNEL   = 1; // AIN1 <- photodiode B (near the LED)
const float ADS1115_LSB_VOLTS = 4.096 / 32768.0; // Gain = +/-4.096V (config below)

// ------------------- EEPROM MEMORY ADDRESSES -------------------
const int CLEAR_INDEX_ADDRESS     = 0;
const int MEDIUM_INDEX_ADDRESS    = 4;
const int TURBID_INDEX_ADDRESS    = 8;
const int CALIBRATED_FLAG_ADDRESS = 12; // Flag: 1 = already calibrated before

// ------------------- CALIBRATION VARIABLES (TURBIDITY INDEX, NOT NTU) -------------------
float clearWaterIndex  = 0.05;  // Default value until calibrated
float mediumWaterIndex = 0.25;  // Default value until calibrated
float turbidWaterIndex = 0.60;  // Default value until calibrated

float HIGH_TURBIDITY_THRESHOLD;
float MEDIUM_TURBIDITY_THRESHOLD;

// ------------------- CALIBRATION STATE VARIABLES -------------------
bool calibrating = false;
int  calibrationStep = 0; // 0=inactive, 1=clear water, 2=medium water, 3=turbid water


void setup() {
  Serial.begin(9600);
  Wire.begin();

  pinMode(LED_DRIVE_PIN, OUTPUT);
  digitalWrite(LED_DRIVE_PIN, LOW);

  pinMode(RED_LED_PIN, OUTPUT);
  pinMode(YELLOW_LED_PIN, OUTPUT);
  pinMode(GREEN_LED_PIN, OUTPUT);
  turnOffAllLeds();

  loadCalibrationFromEEPROM();
  recalculateThresholds();

  Serial.println("============================================");
  Serial.println(" Discrete 90-degree turbidity sensor");
  Serial.println(" Reporting a relative TURBIDITY INDEX (not NTU)");
  Serial.println(" Type 'C' + Enter to start calibration");
  Serial.println("============================================");
}


void loop() {

  if (Serial.available() > 0) {
    char receivedKey = Serial.read();
    processKey(receivedKey);
  }

  float measurementSignal, referenceSignal;
  float index = readTurbidityIndex(measurementSignal, referenceSignal);

  Serial.print("Scatter: ");
  Serial.print(measurementSignal, 4);
  Serial.print(" V | Reference: ");
  Serial.print(referenceSignal, 4);
  Serial.print(" V | Index: ");
  Serial.print(index, 4);

  if (calibrating) {
    Serial.print("   [CALIBRATING - Step ");
    Serial.print(calibrationStep);
    Serial.println(" of 3]");
  } else {
    Serial.print("  |  Status: ");
    evaluateLeds(index);
  }

  delay(300);
}


// ============================================================
//              SENSOR READING (LED ON/OFF DIFFERENCING)
// ============================================================

// Reads both photodiode channels with the LED off, then with the LED on,
// and returns the ambient-corrected ratio (scattered / reference).
// Also returns the two corrected signals (in volts) via the reference args,
// mainly for debugging/logging over Serial.
float readTurbidityIndex(float &measurementSignalOut, float &referenceSignalOut) {
  digitalWrite(LED_DRIVE_PIN, LOW);
  delay(LED_SETTLE_MS);
  float darkMeasurement = readAveragedChannel(MEASUREMENT_CHANNEL);
  float darkReference   = readAveragedChannel(REFERENCE_CHANNEL);

  digitalWrite(LED_DRIVE_PIN, HIGH);
  delay(LED_SETTLE_MS);
  float litMeasurement = readAveragedChannel(MEASUREMENT_CHANNEL);
  float litReference   = readAveragedChannel(REFERENCE_CHANNEL);

  digitalWrite(LED_DRIVE_PIN, LOW); // off between cycles

  float measurementSignal = litMeasurement - darkMeasurement;
  float referenceSignal   = litReference - darkReference;

  measurementSignalOut = measurementSignal;
  referenceSignalOut = referenceSignal;

  // Guard against divide-by-zero / a disconnected or dead reference channel
  if (referenceSignal < 0.001) {
    return 0.0;
  }
  return measurementSignal / referenceSignal;
}

// Reads one ADS1115 channel multiple times and returns the average in volts
float readAveragedChannel(int channel) {
  long sum = 0;
  for (int i = 0; i < SAMPLES_PER_READING; i++) {
    sum += readADS1115Raw(channel);
  }
  float averageRaw = sum / (float)SAMPLES_PER_READING;
  return averageRaw * ADS1115_LSB_VOLTS;
}

// Triggers a single-shot conversion on the given single-ended channel (0-3)
// and returns the raw 16-bit signed result. Talks to the ADS1115 directly
// over I2C, no external library needed.
int16_t readADS1115Raw(int channel) {
  // Config register bits:
  //   OS=1 (start), MUX=100+channel (single-ended vs GND),
  //   PGA=001 (+/-4.096V), MODE=1 (single-shot),
  //   DR=100 (128SPS), COMP_QUE=11 (disable comparator)
  uint16_t config = 0x8000;               // OS = 1 (start single conversion)
  config |= (uint16_t)(0x04 + channel) << 12; // MUX
  config |= 0x1 << 9;                     // PGA = +/-4.096V
  config |= 0x1 << 8;                     // MODE = single-shot
  config |= 0x4 << 5;                     // DR = 128SPS
  config |= 0x3;                          // COMP_QUE = disabled

  writeADS1115Register(ADS1115_REG_CONFIG, config);
  delay(9); // ~1 conversion period at 128SPS, plus margin

  return (int16_t)readADS1115Register(ADS1115_REG_CONVERSION);
}

void writeADS1115Register(uint8_t reg, uint16_t value) {
  Wire.beginTransmission(ADS1115_ADDRESS);
  Wire.write(reg);
  Wire.write((uint8_t)(value >> 8));   // MSB
  Wire.write((uint8_t)(value & 0xFF)); // LSB
  Wire.endTransmission();
}

uint16_t readADS1115Register(uint8_t reg) {
  Wire.beginTransmission(ADS1115_ADDRESS);
  Wire.write(reg);
  Wire.endTransmission();

  Wire.requestFrom((int)ADS1115_ADDRESS, 2);
  uint16_t value = 0;
  if (Wire.available() >= 2) {
    value = (uint16_t)Wire.read() << 8; // MSB
    value |= Wire.read();               // LSB
  }
  return value;
}

// ============================================================
//                   CALIBRATION FUNCTIONS
// ============================================================

void processKey(char key) {

  if (key == 'C' || key == 'c') {
    calibrating = true;
    calibrationStep = 1;
    Serial.println();
    Serial.println("### CALIBRATION STARTED ###");
    Serial.println("Step 1/3: Dip the sensor in CLEAR (pure) water.");
    Serial.println("Once the reading stabilizes, type 'F' + Enter.");
  }
  else if ((key == 'F' || key == 'f') && calibrating) {
    float measurementSignal, referenceSignal;
    float currentIndex = readTurbidityIndex(measurementSignal, referenceSignal);

    if (calibrationStep == 1) {
      clearWaterIndex = currentIndex;
      Serial.print("Value fixed for CLEAR WATER: ");
      Serial.println(currentIndex, 4);
      Serial.println("Step 2/3: Dip the sensor in WATER WITH YELLOW DYE.");
      Serial.println("Once the reading stabilizes, type 'F' + Enter.");
      calibrationStep = 2;
    }
    else if (calibrationStep == 2) {
      mediumWaterIndex = currentIndex;
      Serial.print("Value fixed for MEDIUM (yellow) WATER: ");
      Serial.println(currentIndex, 4);
      Serial.println("Step 3/3: Dip the sensor in WATER WITH COFFEE/DARK INK.");
      Serial.println("Once the reading stabilizes, type 'F' + Enter.");
      calibrationStep = 3;
    }
    else if (calibrationStep == 3) {
      turbidWaterIndex = currentIndex;
      Serial.print("Value fixed for TURBID (dark) WATER: ");
      Serial.println(currentIndex, 4);
      Serial.println("All 3 points have been fixed.");
      Serial.println("Type 'X' + Enter to FINISH and save the calibration.");
      calibrationStep = 4;
    }
    else {
      Serial.println("You already fixed the 3 points. Type 'X' to finish.");
    }
  }
  else if ((key == 'X' || key == 'x') && calibrating) {
    if (calibrationStep < 4) {
      Serial.println("You haven't fixed the 3 points with 'F' yet. Can't finish yet.");
    } else {
      recalculateThresholds();
      saveCalibrationToEEPROM();
      calibrating = false;
      calibrationStep = 0;
      Serial.println("### CALIBRATION FINISHED AND SAVED TO MEMORY ###");
      Serial.println("Returning to normal operation...");
      Serial.println();
    }
  }
}

// Calculates the LED thresholds as midpoints between the 3 calibrated samples
void recalculateThresholds() {
  MEDIUM_TURBIDITY_THRESHOLD = (clearWaterIndex + mediumWaterIndex) / 2.0;
  HIGH_TURBIDITY_THRESHOLD   = (mediumWaterIndex + turbidWaterIndex) / 2.0;
}

void saveCalibrationToEEPROM() {
  EEPROM.put(CLEAR_INDEX_ADDRESS, clearWaterIndex);
  EEPROM.put(MEDIUM_INDEX_ADDRESS, mediumWaterIndex);
  EEPROM.put(TURBID_INDEX_ADDRESS, turbidWaterIndex);
  EEPROM.put(CALIBRATED_FLAG_ADDRESS, (byte)1);
}

void loadCalibrationFromEEPROM() {
  byte calibratedFlag;
  EEPROM.get(CALIBRATED_FLAG_ADDRESS, calibratedFlag);

  if (calibratedFlag == 1) {
    EEPROM.get(CLEAR_INDEX_ADDRESS, clearWaterIndex);
    EEPROM.get(MEDIUM_INDEX_ADDRESS, mediumWaterIndex);
    EEPROM.get(TURBID_INDEX_ADDRESS, turbidWaterIndex);
    Serial.println("A previously saved calibration was loaded.");
  } else {
    Serial.println("No saved calibration found. Using default values.");
  }
}

// ============================================================
//                     STATUS LED FUNCTIONS
// ============================================================

void turnOffAllLeds() {
  digitalWrite(RED_LED_PIN, LOW);
  digitalWrite(YELLOW_LED_PIN, LOW);
  digitalWrite(GREEN_LED_PIN, LOW);
}

void evaluateLeds(float index) {
  if (index > HIGH_TURBIDITY_THRESHOLD) {
    digitalWrite(RED_LED_PIN, HIGH);
    digitalWrite(YELLOW_LED_PIN, LOW);
    digitalWrite(GREEN_LED_PIN, LOW);
    Serial.println("HIGH TURBIDITY - RED LED");
  }
  else if (index > MEDIUM_TURBIDITY_THRESHOLD) {
    digitalWrite(RED_LED_PIN, LOW);
    digitalWrite(YELLOW_LED_PIN, HIGH);
    digitalWrite(GREEN_LED_PIN, LOW);
    Serial.println("MEDIUM TURBIDITY - YELLOW LED");
  }
  else {
    digitalWrite(RED_LED_PIN, LOW);
    digitalWrite(YELLOW_LED_PIN, LOW);
    digitalWrite(GREEN_LED_PIN, HIGH);
    Serial.println("LOW TURBIDITY - GREEN LED");
  }
}

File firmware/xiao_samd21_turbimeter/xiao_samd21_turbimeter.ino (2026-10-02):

#include <Wire.h>

// XIAO SAMD21: D4=SDA, D5=SCL, D7=LED control. All logic is 3.3 V.
constexpr uint8_t LED_PIN = 7;
constexpr uint8_t ADS_ADDRESS = 0x48; // ADS1115 ADDR tied to GND
constexpr uint8_t SAMPLES = 4;
constexpr uint8_t LED_SETTLE_MS = 5;
constexpr int8_t SCATTER_POLARITY = 1; // Use -1 if this amplifier output falls with light
constexpr int8_t REFERENCE_POLARITY = 1;
constexpr int16_t MIN_REFERENCE_COUNTS = 8; // Tune after measuring dark noise
constexpr int16_t SATURATION_COUNTS = 26000; // ~3.25 V at +/-4.096 V PGA

struct OpticalReading {
  int32_t darkScatter;
  int32_t litScatter;
  int32_t darkReference;
  int32_t litReference;
  float ratio;
};

char command[24];
uint8_t commandLength = 0;
bool commandOverflow = false;
const char *adcError = "ADC_IO";

bool readRegister(uint8_t reg, uint16_t &value) {
  Wire.beginTransmission(ADS_ADDRESS);
  Wire.write(reg);
  if (Wire.endTransmission(false) != 0) {
    adcError = "ADC_READ";
    return false;
  }
  if (Wire.requestFrom(static_cast<int>(ADS_ADDRESS), 2) != 2) {
    adcError = "ADC_READ";
    return false;
  }
  value = static_cast<uint16_t>(Wire.read()) << 8;
  value |= Wire.read();
  return true;
}

bool readChannel(uint8_t channel, int16_t &value) {
  // Single-ended AIN0/AIN1, +/-4.096 V, single shot at 128 samples/s.
  const uint16_t config = 0x8000 | (static_cast<uint16_t>(4 + channel) << 12)
      | 0x0200 | 0x0100 | 0x0080 | 0x0003;
  Wire.beginTransmission(ADS_ADDRESS);
  Wire.write(0x01);
  Wire.write(config >> 8);
  Wire.write(config & 0xff);
  const uint8_t transmission = Wire.endTransmission();
  if (transmission != 0) {
    adcError = transmission == 2 ? "ADC_MISSING" : "ADC_CONFIG";
    return false;
  }

  uint16_t state = 0;
  bool ready = false;
  for (uint8_t elapsed = 0; elapsed < 20; ++elapsed) {
    delay(1);
    if (!readRegister(0x01, state)) return false;
    if (state & 0x8000) {
      ready = true;
      break;
    }
  }
  if (!ready) {
    adcError = "ADC_TIMEOUT";
    return false;
  }
  uint16_t raw = 0;
  if (!readRegister(0x00, raw)) return false;
  value = static_cast<int16_t>(raw);
  return true;
}

bool readPair(int16_t &scatter, int16_t &reference) {
  return readChannel(0, scatter) && readChannel(1, reference);
}

bool measure(OpticalReading &reading, const char *&error) {
  uint16_t adcConfig = 0;
  if (!readRegister(0x01, adcConfig)) {
    error = "ADC_MISSING";
    return false;
  }

  int32_t darkScatter = 0, litScatter = 0, darkReference = 0, litReference = 0;
  error = nullptr;
  digitalWrite(LED_PIN, LOW);
  delay(LED_SETTLE_MS);
  for (uint8_t i = 0; i < SAMPLES; ++i) {
    int16_t scatter = 0, reference = 0;
    if (!readPair(scatter, reference)) {
      error = adcError;
      break;
    }
    if (scatter >= SATURATION_COUNTS || reference >= SATURATION_COUNTS) {
      error = "SATURATED";
      break;
    }
    darkScatter += scatter;
    darkReference += reference;

    digitalWrite(LED_PIN, HIGH);
    delay(LED_SETTLE_MS);
    if (!readPair(scatter, reference)) {
      error = adcError;
      break;
    }
    if (scatter >= SATURATION_COUNTS || reference >= SATURATION_COUNTS) {
      error = "SATURATED";
      break;
    }
    litScatter += scatter;
    litReference += reference;
    digitalWrite(LED_PIN, LOW);
    delay(LED_SETTLE_MS);
  }
  digitalWrite(LED_PIN, LOW);
  if (error) return false;

  reading.darkScatter = darkScatter / SAMPLES;
  reading.litScatter = litScatter / SAMPLES;
  reading.darkReference = darkReference / SAMPLES;
  reading.litReference = litReference / SAMPLES;
  const int32_t scatterSignal = SCATTER_POLARITY * (reading.litScatter - reading.darkScatter);
  const int32_t referenceSignal = REFERENCE_POLARITY * (reading.litReference - reading.darkReference);
  if (referenceSignal < MIN_REFERENCE_COUNTS) {
    error = "REFERENCE_LOW";
    return false;
  }
  if (scatterSignal < 0) {
    error = "SCATTER_NEGATIVE";
    return false;
  }
  reading.ratio = static_cast<float>(scatterSignal) / referenceSignal;
  if (reading.ratio > 10000.0f) {
    error = "RATIO_RANGE";
    return false;
  }
  return true;
}

void respond(const char *input) {
  if (strcmp(input, "PING") == 0) {
    Serial.println("TURB1,PONG");
    return;
  }
  if (strcmp(input, "MEASURE") != 0 && strcmp(input, "DIAG") != 0) {
    Serial.println("TURB1,ERROR,BAD_COMMAND");
    return;
  }

  OpticalReading reading;
  const char *error = nullptr;
  if (!measure(reading, error)) {
    Serial.print("TURB1,ERROR,");
    Serial.println(error);
    return;
  }
  if (strcmp(input, "MEASURE") == 0) {
    Serial.print("TURB1,RATIO,");
    Serial.println(reading.ratio, 4);
  } else {
    Serial.print("TURB1,DIAG,");
    Serial.print(reading.darkScatter);
    Serial.print(',');
    Serial.print(reading.litScatter);
    Serial.print(',');
    Serial.print(reading.darkReference);
    Serial.print(',');
    Serial.print(reading.litReference);
    Serial.print(',');
    Serial.println(reading.ratio, 4);
  }
}

void setup() {
  pinMode(LED_PIN, OUTPUT);
  digitalWrite(LED_PIN, LOW);
  Wire.begin();
  Serial.begin(115200); // USB CDC; no wait for the host
}

void loop() {
  while (Serial.available()) {
    const char ch = Serial.read();
    if (ch == '\r') continue;
    if (ch == '\n') {
      if (!commandOverflow && commandLength > 0) {
        command[commandLength] = '\0';
        respond(command);
      } else if (commandOverflow) {
        Serial.println("TURB1,ERROR,BAD_COMMAND");
      }
      commandLength = 0;
      commandOverflow = false;
    } else if (ch < 32 || ch > 126 || commandLength >= sizeof(command) - 1) {
      commandOverflow = true;
    } else if (!commandOverflow) {
      command[commandLength++] = ch;
    }
  }
}

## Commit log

2026-08-29 Add fictional example content: assembly guide, conceptual design, and mock results
    Placeholder guide, schematic diagram, and simulated citizen science data to use as a template until real content is ready.
    [ejemplo_resultados.csv]
2026-08-29 Add real firmware and KiCad hardware design, remove fictional placeholders
    Firmware for DFRobot SEN0189 + Arduino Nano with interactive serial
    calibration, full KiCad project (schematic, PCB, STEP, gerbers), and a
    build photo. Drops the earlier fictional docs/hardware examples now that
    real content is available, and ignores KiCad backup/cache files.
    [ejemplo_resultados.csv, esque.kicad_pcb, esque.kicad_sch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]
2026-08-30 Add rotating PCB render and firmware code explanation
    Turntable GIF of the PCB (rendered from hardware/esque.step via kicad-cli)
    embedded in the README, plus docs/firmware.md walking through the
    turbidity-sensor firmware logic and calibration flow.
2026-08-30 Add BOM with photos/purchase links, fold firmware explanation into README
    docs/BOM.md lists every real component from the KiCad schematic (via
    kicad-cli sch export bom) with a product photo and a purchase link from an
    official/reputable retailer for each. README now includes the full
    firmware walkthrough directly (previously only linked to docs/firmware.md)
    plus a table of contents and a BOM quick-reference table.
2026-09-02 Add 3D print STL previews, assembly photo, embedded code, and reference diagrams
    - 3D/*.stl: printable enclosure parts (CAJA, TAPA, CUELLO, PORTA-SENSOR)
    - img/3d/*.gif: Blender-rendered turntable preview per STL part
    - img/cuerpo.png: assembly render (Nano + sensor holder on the 3D-printed case)
    - README: BOM quick table now has product photos + buy links, full
    firmware.ino embedded in a collapsible code block (native GitHub copy
    button), and official reference diagrams (Nano pinout, sensor wiring,
    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
    [CAJA.stl, CUELLO.stl, PORTA-SENSOR.stl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]
2026-09-02 Add official datasheets for Arduino Nano and DFRobot SEN0189
    Downloaded from the manufacturer/authorized-distributor sources already
    linked in README and docs/BOM.md, so the links there now resolve to files
    in the repo instead of 404ing.
2026-09-02 Translate repo to English, add real prototype photo, drop status section
    - README.md, docs/BOM.md, docs/firmware.md: fully translated to English
    - firmware/firmware.ino: comments, Serial output, and identifiers
    (variables/functions/constants) translated to English, same logic
    - Renamed asset files to English names (3D/*.stl, img/3d/*.gif,
    img/assembly.png, img/pcb_rotation.gif) and updated all references
    - img/prototype.jpeg: real photo of the physical build (renamed from the
    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
    [CASE.stl, LID.stl, NECK.stl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]
2026-09-06 Redesign sensor: discrete 90° nephelometric optics instead of SEN0189
    The DFRobot SEN0189 (0° transmittance, 10-bit ADC, no LED-drift
    compensation) is being replaced with a custom optical bench: an IR LED
    + photodiode at 90° (real ISO 7027-style nephelometry) plus a reference
    photodiode near the LED to cancel brightness drift, both read through an
    external ADS1115 16-bit ADC via raw I2C (no added library dependency).
    - firmware/firmware.ino: new discrete-sensor firmware (LED on/off
    differencing for ambient cancellation, ratiometric turbidity index,
    same 3-point calibration wizard/EEPROM/status-LED UX as before)
    - firmware/legacy_sen0189/firmware.ino: old SEN0189 firmware, kept for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
    [firmware.ino]
2026-09-06 Source optical redesign BOM from amazon.it, add 8-unit shopping list
    Replaces the rough $6-10/unit cost estimate with real amazon.it prices
    and pack sizes for every new component (IR LED, BPW34, TL072, ADS1115,
    status LEDs, headers, jumpers), excluding the Arduino Nano and resistors
    the project already has on hand. Adds a concrete shopping list computing
    exactly how many packs to buy for a batch of 8 units (~€140.58 total,
    ~€17.60/unit).
2026-09-06 Add new discrete-optics components and 8-unit shopping list to docs/BOM.md
    Mirrors the amazon.it-sourced parts table and cost breakdown from
    docs/optical-design.md directly in the main BOM doc, alongside the
    legacy SEN0189 table (now clearly marked as superseded).
2026-09-06 Simplify docs/BOM.md to just the shopping list
    Stripped it down to the amazon.it parts table (photo, price, pack size,
    link) and the 8-unit total — dropped the legacy SEN0189 schematic table,
    reference diagrams, datasheets and notes sections. README's BOM blurb
    updated to match what the file actually contains now.
2026-09-06 Add plain-text version of the BOM shopping list
    Same content as docs/BOM.md, formatted as plain text for teammates
    without a markdown viewer.
2026-09-29 Document USB-C prototype and add one-unit purchase list
    [shopping-list-prototype-usb-c.xlsx]
2026-10-02 Add Android USB-C turbimeter app prototype
2026-10-05 Finish Play listing assets and sensor state
2026-10-12 Update two-board hardware design to revision 0.9
2026-10-12 Refresh project overview and replace enclosure models
2026-10-26 Organize project, add calibration app and record prototype bench results
2026-11-08 Add assembly and app guides and update enclosure models
